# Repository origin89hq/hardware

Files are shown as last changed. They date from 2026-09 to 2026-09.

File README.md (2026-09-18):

<picture>
  <source media="(prefers-color-scheme: dark)" srcset="https://raw.githubusercontent.com/origin89hq/brand/main/logos/origin89-horizontal-white.svg">
  Origin89
</picture>

# Origin89 hardware

The boards and the enclosure of the Origin89 controller: a box that starts a
generator and manages a battery bank at a site four hours from a road, through
a Canadian winter, with nobody watching it fail. The reasoning behind the
circuits is in [docs/DESIGN.md](docs/DESIGN.md), the rules each board keeps
are beside the board, and this repository holds what was drawn from them and
what a fab needs.

| Board | Stage | Files |
| --- | --- | --- |
| [Controller, board A](boards/controller-a/) | prototype: revision A on the bench, the radios receive, board B's interlock not yet proven | EasyEDA source, Gerbers, BOM, pick-and-place, STEP, DXF, fabrication drawing |
| [Generator, board B](boards/generator-b/) | prototype: five boards assembled; the relay chains need a four-link rework, after which the interlock passes on the bench | EasyEDA source, Gerbers, BOM, pick-and-place, STEP, DXF |
| [Enclosure](enclosure/) | drawn, printing waits on a measured board | FreeCAD source, Blender presentation scene |

Nothing here is a validated product. A board that has been fabricated has not
necessarily been measured, and one that has been measured has not been
through a winter.

## Layout

Each board has a README with its status and revisions, its design source
under `easyeda/`, dated fabrication exports under `build/<date>/`, and, once a
board is on the bench, dated session write-ups under `bench/`. A file
that has been filed never changes: a changed export goes beside the old one
under a new date, so a board in someone's hands can still be matched to its
files. The STEP models are in Git LFS; install `git-lfs` before cloning or
they come down as pointer files.

EasyEDA names its exports after the board number and the date and puts them
in directories with parentheses. Do not file them by hand:

```sh
python tools/import_easyeda_export.py controller-a ~/Downloads/PCB1_2026-09-15
```

reads the date from the filenames, writes `build/2026-09-15/` with the same
names every export gets, `gerber.zip`, `bom.csv` and `bom.xlsx`,
`pick-and-place.csv`, `schematic.pdf`, `fabrication-layers.pdf`, `board.step`
and `board.dxf`, puts the `.eprj2` project under `easyeda/`, and refuses a
file it does not recognise or one that would change what is already filed.
Filing the 2026-09-09 exports through it reproduces the committed files byte
for byte, which is the check that the convention is the script and not a
memory.

## Checks

```sh
pip install gerbonara shapely
python tools/validate_gerbers.py boards/controller-a/gerber-rules.json boards/controller-a/build/2026-09-09/gerber.zip
```

It reads the copper layer by layer and reports each rule by number, so a
failure names the hole or the band. Which holes, which keep-out radius and
which voids come from the board's `gerber-rules.json`, so the same script
checks the [camera board](https://github.com/origin89hq/camera) against its
own rules. It runs in CI on every push against the newest controller export.

## Licence

The design files, drawings and CAD are under the CERN Open Hardware Licence
version 2, weakly reciprocal ([LICENSE](LICENSE)): change the board and share
the change; build a product around it and keep the rest of that product to
yourself. The Python tools are under MIT OR Apache-2.0 ([LICENSE-MIT](LICENSE-MIT),
[LICENSE-APACHE](LICENSE-APACHE)). The Origin89 name and marks are not covered
by either; see the [brand repository](https://github.com/origin89hq/brand).

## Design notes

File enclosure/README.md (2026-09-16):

# Enclosure

The controller's shell, printed in MJF PA12, drawn around the finished board:
the board is the master dimension. `shoe.py` is the parametric FreeCAD source
for both boards' plates and shoes; `artwork.py` produces the face artwork and
the label strips; `insert_drawing.py` places the heat-set inserts. Run them
with `freecadcmd`:

```sh
freecadcmd enclosure/shoe.py      # writes enclosure/out/board-{a,b}-{plate,shoe}.stl
freecadcmd enclosure/artwork.py   # writes enclosure/out/artwork-*.{svg,png}
```

Printing waits on a measured board. [`blender/`](blender/) holds the
presentation scene built from these outputs and board A's STEP, which the
website renders from; [`render/`](render/) is the chain that builds it.

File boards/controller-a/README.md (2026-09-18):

# Origin89 Controller, board A

 First revision fabricated. On the bench since 2026-09-14: SWD, both crystals, the RTC and its backup cell, FRAM, NOR, CAN in loopback, the analogue inputs, the watchdog, RS-485 across all three channels, three DS18B20s and the ESP32's radio receive all pass. Switching the ESP32 rail after ten minutes off corrupted the MCU 22 times out of 22 and is open; brown-out is unmeasured; board B's interlock waits on a board B wiring fault.

This is the board that makes the decisions. An STM32G0B1 runs the control
logic; an ESP32-C6 module carries the radio; three RS-485 channels, one CAN
bus and two VE.Direct ports talk to the site's equipment; 1-Wire reads
temperature probes; FRAM and NOR flash hold state and the event log. It runs
from a 12 V battery bank directly. The generator contact is on
[board B](../generator-b/README.md), so no single fault on this board can
hold a genset running.

100 × 125 mm, 1.6 mm FR-4, four M3 mounting holes. All field wiring enters on
one edge through one gland plate.

Design source: [`easyeda/origin89-controller.eprj2`](easyeda/), the EasyEDA
Pro project of this board alone.
Fabrication outputs: [`build/2026-09-09/`](build/2026-09-09/), Gerbers,
[bill of materials](build/2026-09-09/bom.csv),
[pick-and-place](build/2026-09-09/pick-and-place.csv), schematic PDF, STEP
and DXF.
Rules the layout has to keep, numbered and with their reasons:
[LAYOUT-REQUIREMENTS.md](LAYOUT-REQUIREMENTS.md).
Firmware: [origin89hq/firmware](https://github.com/origin89hq/firmware); its
`docs/ARCHITECTURE.md` is the system design this board implements.

## Status of the exports

`build/2026-09-09/` is the export of this layout from the project that
holds the board alone. The revision A boards, the first JLCPCB order, were
made from the same layout exported nine days earlier from the project that
also held the generator and camera; that file differs from this Gerber set
only in 2 mm² of unconnected top-copper islands near (+17.8, −42.1), and
both pass `tools/validate_gerbers.py`. The fab's production package is kept
outside this repository with the rest of the order paperwork.

The pick-and-place is the one to assemble from: the crystal X1 moved 0.112 mm
in X after the first pick-and-place was written, and this file has it where
the boards were assembled. The STEP is in millimetres and carries every part
but U8, the chip antenna, which has no model; CN9's model was not a STEP one
at export time, so check its height against the JST drawing before trusting
the enclosure clearance there. `board.dxf` holds every layer in one file.

The mounting holes on the fabricated boards carry no copper on any layer,
read from the fab's own CAM: the two in the antenna band have nothing within
4 mm, and the two at the bottom edge meet the ground pour at the A-02
keep-out radius, under solder mask. A-03 holds.

## Revisions

| Revision | Export | What changed |
| --- | --- | --- |
| A | 2026-09-09 | First fabrication at JLCPCB, from this layout. Gerber check all clear. First bench session on 2026-09-14: both processors boot; SWD, both crystals, the RTC, FRAM, NOR, CAN in loopback, the analogue inputs, the watchdog, RS-485 between all three channels at 115200 8N1 and 9600 8N2, a DS18B20, the RTC across a power loss on its CR2032, and the ESP32's rail and UART to the MCU work. As built, the STM32 cannot program the ESP32 over serial, because the module's IO8 boot strap is unconnected; with IO8 held high by a hand-held wire to a 4.7 kΩ pull-up, the ESP32 entered serial download mode, took its first firmware through the STM32, and from then on restarted into download mode on command with no wire. The ESP32 received 11 Wi-Fi networks and 30 BLE devices. Board B's interlock could not be proven because board B's relay chains cannot close ([board B bench log](../generator-b/bench/2026-09-14.md)); brown-out is not yet measured, and a self-test crash at the ESP32 rail switch is open ([bench log](bench/2026-09-14.md)). Silkscreen check against the rev B rule `A-33`: fails, the silkscreen carries designators only (#12). |

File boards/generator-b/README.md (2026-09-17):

# Origin89 generator board, board B

 First boards assembled. On the bench since 2026-09-14: both relay chains skip the relay commons as built, so nothing closes. With four links per board, 4 to 6 and 13 to 11 on each relay, the interlock passes: 68 sequences, no failures, the contact dropping 4.34 s after the last kick ([2026-09-17](bench/2026-09-17.md)).

This board owns the generator contact. Board A asks for the engine over a
five-wire link with two logic lines, `RUN` and a once-a-second `KICK`; this
board closes a dry contact toward the genset's two-wire start input only while
both are true, through two relays in series driven by two different paths. A
stuck controller, a stuck GPIO or a lost link each opens at least one relay by
construction, and the relays' second poles report what the contacts did. There
is no microcontroller on it.

80 × 55 mm, two layers, contact nets 1.0 mm wide and held 1.5 mm from every
other net by a DRC rule, seven test pads.

Design source: [`easyeda/origin89-generator.eprj2`](easyeda/), the EasyEDA
Pro project of this board alone.
What it is and why, the `B-nn` rules and what the bench has to prove on the
first boards: [GENERATOR-BOARD.md](GENERATOR-BOARD.md).

Fabrication outputs, export of 2026-09-09: [`build/2026-09-09/`](build/2026-09-09/),
the Gerbers, the [bill of materials](build/2026-09-09/bom.csv), the
[pick-and-place](build/2026-09-09/pick-and-place.csv), the schematic PDF,
the STEP model with every part on it, and one DXF of every layer.

## Status

Schematic drawn and verified, PCB placed and routed, DRC clean. Five boards
ordered from JLCPCB and assembled. Bench proof happens on those boards. The
Gerber check in `tools/` has no rule file for this board yet; this board's
`B-nn` rules are checked on the bench.

First bench contact, 2026-09-14 ([bench log](bench/2026-09-14.md)): driven
from board A, both coils energize and both relays click, but the contact chain
and the feedback chain are wired from each relay pole's NC terminal to its NO
terminal (pins 6 to 8 and 11 to 9), and the commons, pins 4 and 13, are
unconnected. Neither chain can close. A rework of four wire links is proposed
and not yet tried.

## Revisions

| Revision | Export | What changed |
| --- | --- | --- |
| first boards | 2026-09-09 | Gerbers and BOM of the layout the five assembled boards were made from; pick-and-place, schematic, STEP and DXF exported the same day. Bench, 2026-09-14: K1 and K2 are wired NC to NO with their commons unconnected, so CN10 and `FEEDBACK` cannot close ([bench log](bench/2026-09-14.md)). |

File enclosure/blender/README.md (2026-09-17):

# Blender presentation scene

`origin89.blend` is the controller as the website and documentation show it:
the enclosure meshes from `shoe.py`, board A imported from its STEP, the
satin-black finish, both label options, editable cable curves, ten cameras
and a studio light rig. Textures and the Michroma font are packed into the
file. It is stored in Git LFS; install `git-lfs` before cloning.

It is a presentation of the drawn design, not evidence about a board. Change
dimensions in `shoe.py` and rebuild; use Blender for finish, cables, lights
and cameras.

## Controls

Select **O89 Controls** in the Outliner, then open **Object Properties → Custom
Properties**:

| Control | Use |
| --- | --- |
| `production_label` | Switch between the clean editable text and the production transfers from `artwork.py`, including their QR code and specification table. |
| `cover_lift_mm` | Lift the cover, its labels and its light pipe to expose the PCB. |
| `show_enclosure` | Hide the cover and mounting plate for a board-only view. |
| `show_cables` | Hide the harness. |
| `show_bus_layout` | Replace the harness with an illustrative RS-485 daisy chain and 1-Wire trunk with short sensor taps. Use the Wiring camera. |
| `show_cable_sleeve` | Hide or show the braided sleeve and side retaining straps. The jacketed cables inside stay editable. |
| `led_on` | Toggle the single status indicator. |

The numbered collections separate CAD, PCB, connector proxies, clean text,
production artwork, cables, lights and cameras. Move the whole product with
`Product | move or rotate the whole controller`. Units display millimetres;
one internal Blender unit is one metre.

The saved scene uses the Hero camera. The others show the front, left and
right ports, the PCB, the exploded assembly, cable detail, connector
inspection, harness and wiring. **Connector inspection** lifts the cover
18 mm, so from that camera the port labels appear one position left of their
plugs; the closed views line up. **Wiring** shows one RS-485 bus serving
three example devices and one 1-Wire bus serving three probes; the device
shapes and distances are illustrative.

## Render

These commands read the saved `.blend` and never save over it. Run them from
the repository root. Tested with Blender 5.2.1 LTS.

```sh
blender --background --python-exit-code 1 \
  --python enclosure/blender/render_scene.py -- --view hero --studio
```

`--view` is one of `hero`, `front`, `left`, `right`, `pcb`, `exploded`,
`cables`, `wiring`, `connectors` or `harness`. `--label clean|production`
overrides the saved label choice, `--led-on`/`--led-off` the status light.
Omitting `--studio` gives a transparent PNG. Use `--scene` for a saved
variant, `--size 960 --samples 32` for a draft and `--output` to choose the
destination; the default is the ignored `previews/` directory. Each render
writes a JSON file with its camera, controls and projected light-pipe
position. Cable detail, connector inspection, harness and wiring use a 16:10
frame.

The website's Controller film, stills and 3D model are rendered from this file
by the scripts in [`web/`](web/); the website records the file's SHA-256 beside
them.

## Cable presentation

The three RS-485 leads and the bottom 1-Wire lead have graphite Cat5e jackets
(illustrative 5.2 mm diameter), an exposed twisted pair and a third conductor.
The 12 V lead has a separate power jacket with red/black conductors. CAN,
VE.Direct and the left-side leads keep their own cable types. LNK needs the
VH harness specified in `boards/generator-b/GENERATOR-BOARD.md`; Cat5e is
not a substitute for these leads.

Below the connector branches, the jacketed leads gather inside one charcoal
braided sleeve, about 25 mm outside diameter. Sleeve size, weave and strap
placement are presentation choices, not manufacturing CAD. The bus layout
view hides the sleeve so its routes stay readable.

The colour convention below is recorded inside the `.blend`. It is **not** an
Ethernet pinout or a published Origin89 wiring standard:

| Port | Pin 1 | Pin 2 | Pin 3 |
| --- | --- | --- | --- |
| RS-485 CN2/CN3/CN4 | Orange: A | White/orange: B | Green: GND |
| 1-Wire CN8 | Orange: OW_VCC | Blue: OW_DATA_F | White/blue: GND |
| CAN CN5, dedicated cable | Grey: CANH | White/grey: CANL | Green: GND |

Pin order and nets were checked against the `PAD_NET` records of the
2026-08-31 EasyEDA project. CN11 on the side and CN8 on the bottom share the
same 1-Wire nets; the layout uses CN8. Unused Cat5e cores stay insulated
inside the jacket.

RS-485 runs device to device with termination at the two bus ends; 1-Wire
uses one trunk with short taps. The scene does not specify distances or cable
suitability. Cat5e differs in impedance from typical 120-ohm RS-485 cable, so
termination and run length must suit the real design. See
[TI's RS-485 design guide](https://www.ti.com/lit/an/slla272d/slla272d.pdf) and
[Analog Devices' long-line 1-Wire guidelines](https://www.analog.com/en/resources/technical-articles/guidelines-for-reliable-long-line-1wire-networks.html).

## Rebuild from the CAD

**Rebuilding replaces the output file.** Save manual Blender edits under
another name first; rendering preserves them.

```sh
python3 enclosure/blender/rebuild.py --refresh-cad \
  --step boards/controller-a/build/<date>/board.step \
  --output enclosure/blender/origin89.blend --overwrite
```

`--refresh-cad` regenerates the enclosure STLs and production artwork from
`shoe.py` and `artwork.py` first; without it, `enclosure/out/` must already
hold them. The chain in [`../render/`](../render/) always refreshes the PCB
and textures. The runner uses the installed FreeCAD and Blender: on macOS the
applications in `/Applications`, overridden by `FREECAD_PYTHON`, `FREECAD_LIB`
and `BLENDER`. A restricted process sandbox can stop FreeCAD's CPU detection
and Blender's initialisation; run the applications normally in that case.

The 2026-08-31 STEP rebuilds in about a minute. The filed 2026-09-09 export
takes about seven and is not ready to replace it: its import leaves hundreds of
connector, header and inductor meshes stacked at the board centre, which the
debris filter in `assembly_glb.py` does not remove because they sit on the
board. Render the `pcb` view and check the centre before committing a rebuild.

## What the saved file was built from

The committed scene (SHA-256
`ba1af6a1d35ab9483d43a325ea3239f1ef33b9b08b4d51e17c7cd068e499e8b3`) was built before this
repository existed and records the paths of that earlier checkout:

- PCB: `3D_PCB1_2026-08-31.step`, SHA-256
  `36dd9b2bd17666da48dedbe704e6ce8f5d29558beba39459faf885ba20ff91f9`, 1,278
  shapes at 0.2 mm tessellation. This export predates the filed and fabricated
  `boards/controller-a/build/2026-09-09/board.step`, and the board's
  components differ between the two.
- Enclosure and artwork: `shoe.py` and `artwork.py` with the same geometry and
  label positions as `enclosure/` here.

A rebuild from `enclosure/` and the 2026-08-31 STEP renders the same as the
saved file, so the scene carries no manual edits beyond `build_scene.py`.

The connector bodies are datasheet envelopes from `shoe.py` with recessed
screw wells, wire-entry bores and hollow JST sockets for readability. They are
proxies; replace them with supplier CAD if exact connector detail matters.
The clean front text is a presentation variant; the fabrication artwork
remains the other label option.

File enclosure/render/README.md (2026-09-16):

# CAD to Blender

These scripts turn the enclosure CAD and a board STEP into the assembly that
[`../blender/build_scene.py`](../blender/build_scene.py) dresses into the
presentation scene. [`../blender/rebuild.py`](../blender/rebuild.py) runs the
whole chain; run the steps by hand only to debug one of them.

Two interpreters, because two ecosystems:

- **FreeCAD's Python** (`/Applications/FreeCAD.app/Contents/Resources/bin/python`)
  for anything that imports `shoe`/`artwork` or reads STEP. Put
  `/Applications/FreeCAD.app/Contents/Resources/lib` on `PYTHONPATH` when
  invoking it directly; the rebuild runner does this.
- **Blender** for assembly and the Cycles scene.

Intermediates land in `work/`, which is ignored and derived.

| # | Script | Runs under | Produces |
|---|---|---|---|
| 0 | `../shoe.py` | FreeCAD | `../out/board-{a,b}-{plate,shoe}.{step,stl}` |
| 1 | `../artwork.py` | FreeCAD | `../out/artwork-*.{svg,png}` |
| 2 | `frames.py` | FreeCAD Python | `work/frames.json`: envelopes, plugs and light pipes in the board frame |
| 3 | `board_glb.py --step <file>` | FreeCAD Python | `work/board-a.glb` and `board-a-source.json`, recording the STEP and its SHA-256 |
| 4 | `strips.py` | FreeCAD Python | `work/strip-*.png` and `strips.json`: one texture per port strip, read from `artwork.py`'s `STRIP_BANDS` |
| 5 | `textures.py` | FreeCAD Python | `work/tex-{a,b}.png`: the top transfers at texture size |
| 6 | `assembly_glb.py` | Blender | `work/assembly.blend` and `boxes-full.glb`: both boxes, boards, plugs, strips and cables |
| 7 | `../blender/build_scene.py` | Blender | `../blender/origin89.blend`: box A in the satin-black studio |

Step 6 still assembles box B, the generator board's enclosure, with an
envelope-only board. Step 7 removes it; `work/assembly.blend` is the place to
start a scene that shows both boxes.

Cycles is deterministic only on one machine with one seed. A re-render on
another machine differs in noise, not in content.

Gotchas that already cost time:

- The glTF exporter composes an unapplied object rotation about the world
  origin. Bake rotation into the mesh (`transform_apply`) before export.
- After a GLB round-trip, transforms are baked into vertices and every object
  origin is the world origin. Dress geometry by editing `v.co`, never
  `obj.scale` or `obj.location`.
- The EasyEDA STEP carries the board slab twice and has no bodies for THT
  connectors (0.8 mm outlines). `assembly_glb.py` keeps the lowest slab and
  stands in the datasheet envelopes from `frames.json`.
- `matrix_world` is stale after moving an object until
  `bpy.context.view_layer.update()`. Measure after the update, or a decal
  lands at the pre-move position.

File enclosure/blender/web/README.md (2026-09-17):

# Website renders

These scripts render the Controller media on the
[website](https://github.com/origin89hq/website)'s homepage: the hero film, the U7
and U8 chip views, the connection and integration stills, the Gerber artwork and
the 3D model. They read [`../origin89.blend`](../origin89.blend) and board A's
filed export in `boards/controller-a/build/2026-09-09/`, and never save over
either. Like the scene, the renders present the drawn design; they are not
evidence about a board.

The website packages the outputs with `apps/website/scripts/package-home-media.mjs`
and records this repository's commit and the SHA-256 of the scene, `gerber.zip`,
`pick-and-place.csv` and `bom.csv` beside them. The site miniatures on the same
page come from origin89hq/brand, `situations/scenes/site-miniatures/`.

| Script | Runs under | Writes |
| --- | --- | --- |
| `gerber_layers.mjs` | Node, through npx | `gerber-layers/`: `top-{copper,pads,silk,board}.png` masks at 64 px/mm and `top-layers.json` |
| `gerber_art.mjs` | Node, through npx | `gerber-art/`: `gerber-u7.webp`, `gerber-board-dim.webp`, `trace-mask-{u7,board}.webp` and `board-albedo.jpg` for the GLB |
| `build_detailed_board.py` | Blender | `controller-detailed.blend`, the scene the renders below use |
| `board_detail.py` | Blender, imported by the script above | parts and the board material |
| `render_film.py` | Blender, on the detailed scene | `film/frame-NNNN.png` (1920 × 1080) and `film/anchors.json` |
| `render_chips.py` | Blender, on the detailed scene | `chips/u7.png` and `chips/u8.png` (1000 × 1000, orthographic) |
| `render_studio.py` | Blender, on the detailed scene | `studio/connect-*.png` (1760 × 1210) and `studio/integrate-controller.png` (1600 × 1800) |
| `export_glb.py` | Blender | `controller-raw.glb`, compressed to `controller.glb` with gltf-transform |

Every Blender render has a transparent film. The detailed scene replaces the
STEP's box components with parts placed from pick-and-place, marked from the
BOM, and textures the board from the Gerber masks. Connectors keep the scene's
datasheet-envelope proxies. The ESP32 module's matrix code is a fixed
pseudo-random pattern. `render_chips.py` scales the laser marking and mattes
the finishes for the flat top view. `render_film.py` moves one camera without
cuts through its stations along periodic curves, bakes every camera, object and
light value on each frame, and renders with motion blur. It projects anchor
points on the board through the camera into `anchors.json`, with the window in
which each callout is shown; the website places its callouts from that file, so
change the stations, windows, anchors and callouts together.

## Run

Requires Blender 5.2 on a Mac with a Metal GPU (the render scripts select Metal
devices), Node with network access for `npx`, the scene from Git LFS, and
Inter Tight 600 for the part markings: `fonts/InterTight-600.ttf` in
origin89hq/brand, also shipped in the `@origin89/brand` package. This
repository has no Node workspace; npx installs the pinned packages for each run.

From the repository root, on a clean checkout:

```sh
M=/tmp/home-media
BLENDER=/Applications/Blender.app/Contents/MacOS/Blender
FONT=/path/to/brand/fonts/InterTight-600.ttf
WEB=enclosure/blender/web

# 1. Gerber masks and artwork
unzip -o boards/controller-a/build/2026-09-09/gerber.zip -d "$M/gerber"
npx --yes --package sharp@0.35.3 --package pcb-stackup@4.2.8 -- \
  node "$WEB/gerber_layers.mjs" --gerbers "$M/gerber" --out "$M/gerber-layers"
npx --yes --package sharp@0.35.3 -- \
  node "$WEB/gerber_art.mjs" --layers "$M/gerber-layers" --out "$M/gerber-art"

# 2. Detailed board scene (keep $M/gerber-layers: the scene links those PNGs)
"$BLENDER" --background --python-exit-code 1 --python "$WEB/build_detailed_board.py" -- \
  --layers "$M/gerber-layers" --font "$FONT" --output "$M/controller-detailed.blend"

# 3. Film, chips and studio stills
"$BLENDER" --background --python-exit-code 1 "$M/controller-detailed.blend" \
  --python "$WEB/render_film.py" -- --out "$M/film"
for chip in U7 U8; do
  "$BLENDER" --background --python-exit-code 1 "$M/controller-detailed.blend" \
    --python "$WEB/render_chips.py" -- --out "$M/chips" --chip "$chip"
done
"$BLENDER" --background --python-exit-code 1 "$M/controller-detailed.blend" \
  --python "$WEB/render_studio.py" -- --out "$M/studio"

# 4. Web model
"$BLENDER" --background --python-exit-code 1 --python "$WEB/export_glb.py" -- \
  "$M/controller-detailed.blend" --board-albedo "$M/gerber-art/board-albedo.jpg" \
  --output "$M/controller-raw.glb"
npx --yes @gltf-transform/cli@4.5.0 webp "$M/controller-raw.glb" "$M/controller-webp.glb"
npx --yes @gltf-transform/cli@4.5.0 meshopt "$M/controller-webp.glb" "$M/controller.glb"
```

Hand `$M` and this checkout to the website packager. It reads `film/`, `chips/`,
`studio/`, `gerber-art/` and `controller.glb`, and `dioramas/` from the brand
script unless `--only` leaves the miniatures out. It refuses scene or fab inputs
that differ from the checked-out commit.

Run one Blender process at a time; the renders share the GPU. The film is 1440
frames (48 s at 30 fps) at 40 samples, about 5 s per frame on an M2 Max, so
about two hours. Check the motion first with `--size 640x360 --samples 8`, about
35 minutes for the whole loop. The render skips frames that already exist, so an
interrupted render resumes. Changing one station only changes the frames from
two stations before it to two stations after it, so delete and render those; `--frames 1-120` renders part of the loop and
`--anchors-only` rewrites `anchors.json` without rendering and reports how much of
each callout window keeps its anchor in frame. The chips and stills (96 samples) take seconds each;
`render_studio.py --only` renders a subset. The Gerber masks take about a minute
of CPU.

With sharp 0.35.3, the two Gerber scripts reproduce the website's current Gerber
artwork byte for byte. New Cycles renders are not expected to match the published
hashes.

A new fabrication export changes the date in three places: `FAB_BUILD` in
`board_detail.py`, the `unzip` path above, and the packager's input paths.
`gerber_layers.mjs` stops if the board outline is no longer 100 × 125 mm, which
the board texture's UV mapping assumes.

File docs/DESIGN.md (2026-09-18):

# Circuit design

Why the circuits are what they are: the generator interface, the power path,
the buses, the parts, and what was checked before any board was laid out. The
rules a layout has to keep are elsewhere and own the values:
[`LAYOUT-REQUIREMENTS.md`](../boards/controller-a/LAYOUT-REQUIREMENTS.md)
(`A-nn`) for board A and
[`GENERATOR-BOARD.md`](../boards/generator-b/GENERATOR-BOARD.md) (`B-nn`) for
board B, each stating what revision A was built with beside a rule revision B
changed. Where a value here has moved since revision A, the rule wins and this
document says so. The system side, what the controller decides and why the
comms processor may not, is the firmware's
[`ARCHITECTURE.md`](https://github.com/origin89hq/firmware/blob/main/docs/ARCHITECTURE.md);
this document does not repeat it.

It grew out of origin89's `CONTROLLER-V1.md` (2026-08-03), split three ways on
[origin89hq/origin89#16](https://github.com/origin89hq/origin89/issues/16): the
circuit reasoning came here (#50), the system design went to the firmware, and
the plan became origin89hq/firmware#3 and its milestones.

## Two boards, and why the split exists

The run-enable watchdog lives on board B with the relays it drops. That is what
makes the split a safety decision rather than a packaging one: the plug between
the boards carries only *please run*, so every way it can fail, a connector
backed out, a cable pulled, a cold joint at −30 °C, stops the kick arriving and
opens the contact. A lost link is the safe state by construction. Put the
watchdog on the controller instead and the same fault is a cracked joint that
nothing announces.

The second reason is dirt. The 60 ft pair to the generator is the filthiest
thing touching this design, and on its own board that energy never reaches the
one carrying the MCU, three RS-485 channels and CAN. `LAYOUT-REQUIREMENTS.md`
§1 states the same split for a layout house.

## The generator interface

### A maintained contact, and a kit that owns the engine

Site A's generator carries a wireless and 2-wire remote-start kit. The kit
maker's own answer, when asked:

> "You can touch the 2 terminals in that connector together with a screwdriver.
> When connection is made between these 2 terminals the generator should crank
> and start. When you release the connection the generator will shut off."

**A maintained contact, not a pulse. Closed is running, open is stopped.** The
kit owns the engine switch, the fuel valve, the choke, the crank sequence and
the retries; the controller owns deciding. So the generator interface is one
dry contact out and one AC meter in, not six inputs and four outputs, and there
is no generator module in V1: a dry contact over 60 ft has no voltage drop and
no comms link to lose. A module becomes a product feature when a run is long
enough that pulling twelve conductors beats pulling one shielded pair, or when
a site has a genset without a start kit. A genset with a controller panel of
its own changes that site from *drive a contact* to *talk to a controller over
Modbus*, which the buses below already carry.

### The electrical design

```text
   board A, controller          │          board B, generator
                                │
STM32 ── RUN ───────────────────┼──► relay B    rev A: RUN drives the coil
      ── KICK ──────────────────┼──► monostable ──► relay A
      ◄─ FEEDBACK ──────────────┤◄── the relays' second poles, in series
         12 V · 0 V ────────────┤
                       CN9, JST VH
                                    relay A ── relay B ── F1 ── CN10 ── 18/2 ── [lockout] ── 2-wire input
```

**Two relays in series, independently driven.** A maintained contact means a
welded relay runs the generator until the tank is empty. One weld no longer
does that. Both welding is still possible, which is what the alarm and the
lockout switch are for. The two-in-series claim holds only if nothing common
can hold both, so the two coils have two drivers from two sources and never a
shared gate net (B-01), and the relays are rotated to each other so a surge
through the pair they share does not find them the same way (B-14).

**A run-enable watchdog in hardware.** The contact stays closed only while
firmware keeps kicking a retriggerable monostable, a 74HC123 whose Q is the
level the relay wants. Firmware that dies stops kicking, the contact opens
after the window, and the generator stops: dead controller means stopped
engine, guaranteed by a part that runs no code. The kick line never reaches a
coil directly, because a `KICK` stuck high is exactly the failure the
monostable exists to catch (B-02). On revision A the window is about 4.5 s by
design and 4.3 s on the bench, inside the 3.0–6.5 s the contract allows and
drifting with board temperature, so the firmware measures what it sees and
never assumes (#22, and the
[bench log of 2026-09-17](../boards/generator-b/bench/2026-09-17.md)).

**The claim the first design made, and revision A did not keep.** The design
said a brief controller reset, a watchdog or a brown-out, would re-kick before
the window expired and the running generator would never notice. Revision A
does the opposite: `RUN` drives relay B's coil directly and holds the
monostable in reset while low, so the moment the controller's pin stops
driving, board B's pull-down reads *stop*, relay B opens and the monostable
clears, and every controller reset opened the contact at once (#18). Revision
B keeps the promise with a latch rather than a delay: relay B follows `RUN`
*sampled on each `KICK` edge*, so a deliberate stop lands within one kick and
only a silent controller rides through, bounded by a window widened to 15 s
(B-19, B-20). The window is budgeted: the controller's 8 s
watchdog at the LSI's worst case, 8.8 s, plus 3 s for reset-to-first-kick,
which the firmware owes as a requirement, plus margin (#51). Revision B is
drawn and not yet proven; B-21 is the table the bench runs against.

**A lockout switch at the generator end.** Open means the software is
physically disconnected regardless of what it believes. It is the service
lockout: cut it before touching the engine and nothing remote can crank it
while your hands are in there. The kit manual's own wiring diagram puts
an emergency stop switch in series in the junction box, which is this switch.
It is a different thing from the auto/off/manual selector at the controller,
which is an operator override; the firmware's `ARCHITECTURE.md` has both.

**Contacts for a dry circuit.** Nobody had measured the 2-wire input's
open-circuit voltage or short-circuit current when the first design was
written, and a low-level dry-circuit load is exactly where ordinary silver
contacts fail to make, because there is not enough energy to break through the
oxide film. A sweep of the remote-start section of every 2-wire generator
controller's manual found each input switched to negative at a few milliamps
behind a pull-up, one maker's at 12 V and 6 mA, another's at 5 V and
current-limited, so
board B carries the G5V-2's gold-clad bifurcated crossbar contacts, specified
from 10 µA to 2 A. That closes the question for the class; the site's own
figures still confirm it, and on revision B they size the clamp (below).

**The fuse and the clamp.** The kit's internal contacts are fused with its own
5 A main fuse and its manual says additional protection may be required, so
the run contact carries its own fuse sized below it: a 2 A 5 × 20 in a holder,
replaceable without a tool, because a soldered fuse four hours from a road is
a dead site and a fuse above the kit's makes the kit's blow inside a box
nobody opens (B-05). Across the pair at the terminal sits a bidirectional TVS,
bidirectional because the input's polarity is never guaranteed. On revision A
it is one part, and a single shorted TVS joins the pair with no relay involved
and the fuse not in the path, the one part outside the interlock that can
start the engine; revision B fits two in series, each blocking the site's
start-input voltage alone (B-06, #19). The 60 ft pair is the surge path, so
its copper is 1.0 mm and nothing else comes within 1.5 mm of it (B-04, B-13).

**The link between the boxes.** Five conductors, `CN9` to `CN9`, a locking
JST VH at both ends, under 3 m, indoors, unshielded: nothing on it carries
more than the two coils. The pin order is board A's and is written on both
silkscreens, because two boards that disagree on a locking connector's pin
order is 12 V on a logic pin with a connector that cannot be plugged the
other way to fix it (B-09). On revision A the three logic lines run straight
from the STM32's pins to the cable, and two of them are the pins ST's system
bootloader drives as FDCAN1 on an empty flash, which every board has before
programming and after an interrupted update: the bootloader pulls `RUN` above
board B's gate threshold and can pulse `KICK`, so the start contact can close
with no firmware running. The monostable guards against a stuck controller,
not against a bootloader that looks like one (#30). Revision B moves the three
nets to pins the bootloader does not configure, behind a series resistor, a
TVS and a pull-down at board A's end (A-34), and the firmware never leaves an
empty-flash window; the firmware's `ARCHITECTURE.md` carries that half.

### Proof of running is measured at the panel

A contact closing is not an engine catching. The `starting` to `running`
transition needs AC the controller can read itself, and the earlier answer, a
smart plug on Wi-Fi, breaks the one rule on the machine where not knowing the
state is most dangerous; the firmware's `ARCHITECTURE.md` makes that argument.
The choices for sensing:

| | | |
|---|---|---|
| **An RS-485 AC meter** at the panel, on the charger's supply | ~$25 | Voltage *and* frequency. "120 V at 60 Hz" is far better evidence an engine caught than "current is flowing" |
| **Optocoupled AC detect** into a GPIO | ~$5 | Simplest and most direct. What the smart plug plan replaced |
| **Charge current on the bank**, via the DC meter already there | free | Indirect, and solar charges too; it cannot tell the two sources apart |

The AC meter is the choice: frequency is the discriminator current alone
cannot provide. Its framing differs from the DC meters', so it cannot share
their bus; which port it takes is in the bus map below. At site
A the generator's 120 V output already runs to the cabin and lands on the
charger outlet, so proof of running is measured there and nothing but the dry
contact pair crosses to the garage.

### What the kit's manual says, and which lines change a design

From the kit's 2-wire installation manual:

> The manufacturer temperature range specification for the choke actuator is
> **−20 °C to +60 °C**. It is not recommended to start the generator with the
> remote start outside this range. **Choke actuator failure may result.**

The coldest night is exactly when the generator is most needed and least able
to be started; that is the central tension of the product stated by the
vendor. It is a behaviour decision, made deliberately and logged with the
outdoor temperature, and it belongs to the firmware (`ARCHITECTURE.md`, the
generator). What it asks of the hardware is an outdoor probe, which the 1-Wire
port carries.

- **"The generator ignition switch MUST be left on for the 2-wire start to
  operate."** Somebody switching it off disables remote start with no
  indication at our end. Proof of running at the panel is what catches it.
- **"Start Module internal contacts are fused with the start module main
  fuse. Additional circuit protection may be required."** The kit ships a 5 A
  fuse; B-05 is the answer.
- The manual states neither the input's open-circuit voltage nor its
  short-circuit current, so the meter is still the only way to learn them.

### Still to confirm at the site

- **Whether opening the 2-wire contact stops a fob-started generator.**
  Release means shut off was described for the 2-wire path only. If the fob
  latches, the firmware's `stop not honoured` is routine rather than rare, and
  the selector's *Off* position is the only honest way to hand control back.
  One email to the kit's maker.
- **The 2-wire input's open-circuit voltage and short-circuit current.** A
  meter across the connector, a minute. It confirms the site sits inside the
  class the G5V-2 covers, and on revision B it sizes each of B-06's two series
  clamps. Still unmeasured.
- **How the cable runs and whether the garage shares the cabin's earth.**
  `LAYOUT-REQUIREMENTS.md` §5 items 5 and 6: aerial means surge protection
  sized for it, buried means rodents, and a detached garage with its own rod
  means the pair bridges two earthing systems.

## Power

### The supply is the bank

The controller runs from the battery bank through its own validated input and
protection path, with no inverter and no computer kept on to host it, because
continuous consumption takes energy from the bank through the season when it
is weakest. Revision A was built for a 12 V bank only, with the bank itself on
the `V12` net; revision B takes a 12 V or a 24 V bank and regulates a 12 V
rail from it for everything past the front end (A-20, A-20e). 48 V banks are
out of scope by decision: such a site already runs its 24 V loads from a
converter of its own, and the controller connects to that (§5 item 11). The
input range has to account for the charging voltage and its transients as
well as the nominal, which is why A-20 is written from the highest voltage a
24 V charger applies with equalisation included.

Measure total input power on the assembled controller for idle, normal
polling, active communications, energised outputs and peak demand, converters,
transceivers and powered peripherals included, and record the communications
state and duty cycle with any daily energy figure. Until those measurements
exist, public copy states the low-consumption goal without a numeric saving or
runtime promise. An MCU's idle current is not the whole device's consumption.

### The rails

Two TPS54331 bucks, 5 V for the transceivers and 3.3 V for everything else.
The 3.3 V converter runs from `V12` directly rather than from the 5 V rail, so
a fault in the transceiver supply cannot take the MCU down with it. On
revision B one 60 V-class buck sits ahead of both and makes the regulated 12 V
they run from; below 12 V it passes the bank through, about 10.2 V at a
discharged 12 V bank, which the TPS54331s regulate from and board B's coils
pull in at (A-20e). Putting that converter on board A rather than on board B
keeps the bank voltage out of the safety chain and board B a 12 V board on
any bank. Every rail that leaves the board, board B's coil supply, the 4-pin
RS-485 port's 5 V, the 1-Wire supply and the tank loop, goes through its own
current limit with a fault flag the MCU can read, so a pinched cable is a
diagnosis and not a blown inlet fuse (A-20b to A-20d, A-24, #47).

The comms processor's 3.3 V is a switched sub-rail, gated by the MCU so a
wedged radio is recoverable without a drive. Revision A's switch defaults off
through every controller reset, which nobody chose, and switching it on after
minutes off corrupted the MCU 22 times of 22 on the bench; revision B's switch
is slew-limited and defaults on, and the controller takes ownership once it
has booted (A-23, §5 item 8, #5). The policy that decides when the radio is
cut is the firmware's, in `ARCHITECTURE.md` under the safety architecture.

### The buck's under-voltage lockout is deliberately low

`EN` divider 330 kΩ / 51.1 kΩ on revision A: the converter starts at 8.99 V and
stops at 8.00 V, about 1 V of hysteresis. Low on purpose, and the reason is the
whole point of the box. The first values, 75 kΩ / 10 kΩ, put the stop
threshold at 10.32 V with only 225 mV of hysteresis: the controller would
power down while the bank still had usable charge, and the controller is the
thing that decides to start the generator that recharges it. It would switch
off at exactly the moment it was most needed and stay off until somebody drove
out. Protecting the bank from deep discharge is the charge controller's
low-voltage disconnect, not the buck's. The thin hysteresis was a second
problem: a bank hovering at the threshold chatters the whole controller.

Computed with TI's equations 1 and 2, which include the internal 1 µA and 3 µA
`EN` current sources; treating `EN` as a plain divider gives a materially
different and wrong answer. Revision B's front-end buck sees the bank instead,
and the same argument sizes its enable network; its values are not yet in the
rules, and the bench measures the brown-out recovery either way (§5 item 9).
The firmware's radio policy has to sit above whichever threshold the front end
stops at, or it never runs.

### The buck's compensation, recomputed

10 kΩ and 10 nF in series on `COMP`, 100 pF from `COMP` to ground, on both
rails. The original 3.09 kΩ / 3.3 nF put the compensation zero at 15.6 kHz
while the loop crossed over at 5.7–9.5 kHz. A zero above crossover boosts
nothing where it matters, and the worst-case phase margin was about 20° on
both rails across the plausible range of ceramic derating and load: a peaky,
ringing rail rather than an obviously dead one, the kind that survives a bench
test and browns out under the comms processor's transmit bursts. Recomputed
against the real 15 µH filter to at least 74°.

The model was checked against the datasheet's own worked example first: it
reproduces TI's 3.3 V design at 22 kHz and 74° against their stated roughly
25 kHz and better than 60°, because a loop model nobody has calibrated is an
opinion. 10 kΩ and 10 nF were already in the BOM and the parts they replaced
were used nowhere else, so the change removed a line rather than adding one.
A-30 puts the network on the `COMP` pin itself, with the 100 pF closest: a
loop with 74° on paper is still a ringing rail if the error amplifier's output
picks up the switch node over 20 mm of trace.

## The buses

### Transceivers go on the board, not on headers

Breakout modules are how the circuit was prototyped. They are not how it
ships. Every connector is a failure point, and a module on pin headers
through a few hundred thermal cycles beside a running generator is an
intermittent fault that presents as a flaky bus and costs a week. Layout
cannot be controlled through wires: the transceiver belongs near the
connector, the TVS at the connector rather than after the chip, the pair
spaced deliberately, the ground reference short. And the transceiver IC costs
a dollar or two against six for the module, before its board, its headers and
somebody plugging it in. What carries across from the bench modules onto the
layout:

| | Why |
|---|---|
| **MAX13487E / MAX13488E**, auto-direction | No DE pin, no turnaround timing to get wrong: one category of bug removed permanently for about $2 a channel. **It does not remove the bias resistors**; see below. The one thing the auto-direction part cannot do is stop driving while the MCU is in reset, so each `TX` net carries a pull-up (A-41, #28) |
| **TVS on A/B, at the connector** | SM712 class: asymmetric 7 V / 12 V, matching RS-485's −7 / +12 V common-mode range, which a symmetric SMAJ12CA does not. **Pin 3 is the common on both the SM712 and the PESD1CAN; the middle pin is a signal line.** Both were first wired with pin 2 to ground, which would have left the A line with no path to ground and a spurious clamp across the pair. Neither symbol names its pins, so the netlist looked plausible and was wrong (A-11c) |
| **Selectable termination**, a header and shunt | Whichever device sits mid-bus must stop terminating without a soldering iron. Shipped fitted, placed above its own connector and silkscreened with the bus name, because the first placement left three of four jumpers nearest a bus they do not terminate (A-13, A-32) |
| **Activity LEDs** | On the receiver output, so they show something *else* on the bus talking, which is what somebody with the cover off wants to know. Revision A's are far brighter than an electrical room needs; revision B drives them at 0.2–0.5 mA (A-14) |

**Slew rate is the one place the two parts differ meaningfully**, and the
intuition is backwards: the MAX13487E's slew limiting exists to reduce
reflections and EMI on long cable, so the *slower* part is the right one for a
long run. Both cover 115200 many times over, so speed decides nothing.

### Bias is mandatory, and 560 Ω was not enough

The MAX13487E datasheet calls the A/B pull-up and pull-down *required for
proper operation*, because the direction state machine reads the current A−B
state and the receiver threshold is ±200 mV, not fail-safe. An unbiased idle
bus is indeterminate and the state machine's own input is undefined. This was
nearly omitted on the belief that the part had a true fail-safe receiver; it
does not.

The first design put 560 Ω to +5 V and to 0 V at the master end, and revision
A was built with it. **Superseded by A-13c.** 560 Ω leaves 254 mV of idle
differential with two terminators and 172 mV with three, inside the undefined
band, and a mid-bus board with its jumper still fitted is the three-terminator
case; two terminators keep only 40–50 mV of margin against noise on a long
cable. Revision B sizes the bias to stay above 200 mV with three terminators,
about 390 Ω, settled on a real cable against the bias of the other devices on
the site's buses before the order (#26).

### The isolated bus is the exception, and none is fitted

The criterion is two separate earthing systems, not distance. A 30 m run
between devices bonded at the same panel shares a ground and needs nothing;
two buildings ten metres apart with a rod each do not, and do. An
ADM2582E-class part, isolated transceiver and isolated DC-DC in one package,
has explicit DE and RE pins; there is no common isolated auto-direction part.
So a bus that crosses an earthing boundary uses the USART's hardware
driver-enable, which the STM32 outputs on the RTS pin (below), and the
firmware supports both modes regardless.

No isolated channel is fitted, deliberately. At site A nothing but the dry
contact pair crosses to the garage, so the bus would have no consumer, and an
ADM2582E with an 8 mm barrier would cost board area for it. A detached garage
with its own rod is what would reopen this (`LAYOUT-REQUIREMENTS.md` §5).

### Bus map

The VE.Direct family is the trap here, and it costs a bench day: those
products do not speak Modbus RTU on RS-485.

| Device | Bus |
|---|---|
| Charge controllers speaking Modbus RTU | RS-485, 115200 8N1 |
| DC meters | RS-485, Modbus RTU, 9600 **8N2**; passive on the bus side and fed 5 V over the cable, so they take the 4-pin port (A-37) |
| The AC meter at the panel | RS-485, 9600 8N1, a third framing, so it cannot share the DC meters' bus |
| Origin89 modules (V2) | RS-485, Modbus RTU, 9600, plus an attention line |
| Most lithium BMSes | CAN, 500 k |
| VE.Can and BMS-Can devices | CAN, 500 k |
| VE.Direct devices: shunts, battery monitors, MPPTs | **VE.Direct**: TTL UART, point to point, one port each |
| VE.Bus inverter-chargers | Proprietary; read through their own gateway over Modbus TCP, a client's job |
| DS18B20 | 1-Wire |

Three RS-485 channels carry three framings, one each. Which connector carries
which is configuration in the firmware, with one constraint the board sets:
the DC meters need the 5 V pin, and only `CN4` has one. Revision A read a DC
meter on that port at 9600 8N2 as soon as it had 5 V from elsewhere, 119 of
120 polls (#34). When the V2 modules arrive they take a channel, and the AC
meter is the port that then gets forgotten until a respin, which is why the
serial budget below counts it.

**Modules speak Modbus, not a house protocol.** The same driver stack then
reads them and third-party gear, any twenty-dollar USB dongle debugs them, and
every Modbus tool becomes test equipment. Keep our own register map; do not
invent framing. Modbus cannot let a leak sensor interrupt, so a shared
open-drain attention line on the same cable does that: any module pulls it low
to mean *poll me now*. One wire, decades old.

### VE.Direct is point to point, and needs isolation

Two VE.Direct ports are where the shunt lives, and the first design priced
them as nearly free, a UART and a level shift. Revision A built them that way,
with 1 kΩ in series and no level shift, listening on pin 3, its own TX
position, so they work only with a straight cable and only with 3.3 V
products. **Superseded by A-38.** The maker's MPPTs drive 5 V, which exceeds
the STM32's pin limit whenever the internal pull-up is on or the board is off,
and its own FAQ asks for galvanic isolation because the product side has
little protection of its own. Revision B listens on pin 2, the producer's TX,
through a digital isolator per port powered from the port's pin 4 within the
port's documented 10 mA limit, working at both levels the products drive, and
defaulting high on the board side while the product side is unpowered so an
unplugged port reads idle by the part's own fail-safe (#27). No VE.Direct
device has been on the bench yet; that is §5 item 9.

### Seven serial ports against eight instances

An earlier draft said the part has six USARTs and treated the budget as
closing at zero margin. It has eight independent serial instances,
USART1/2/3 (FULL), USART4/5/6 (BASIC), LPUART1/2 (LP), per RM0444 Rev 5 Table
179, and the undercount is the only reason this looked tight.

| Port | Instance | Why that one |
|---|---|---|
| ESP32 link, 921600, CTS+RTS | **USART1/2/3** | Only the FULL set has a FIFO. A BASIC instance at 921600 is a byte-at-a-time interrupt storm |
| Isolated bus, hardware DE, if ever fitted | **USART1/2/3** | FULL, and DE needs an instance whose RTS pin is free (below) |
| Two RS-485 channels, auto-direction | USART4/5/6 | No DE and no flow control needed, so BASIC is enough at 9600 |
| **The AC meter, proof of running** | USART4/5/6 | **A seventh port.** 9600 8N1 cannot share the DC meters' 8N2, and once the V2 modules take a channel it cannot share theirs either |
| VE.Direct ×2, RX only | **LPUART1/2** | Needs neither DE nor flow control, and LPUART can run while the core is stopped |
| Console | not a UART | `defmt` over RTT on SWD |

Seven allocated, one spare. Two silicon facts constrain the schematic:

- **The driver-enable signal is output on the RTS pin** (RM0444 §33.7.5,
  `CR3.DEM`). There is no separate DE ball. An instance does hardware RTS *or*
  hardware DE, never both. That does not collide here: the ESP32 link needs
  RTS and CTS and drives no transceiver, and Modbus RTU has no flow control.
  But a schematic drawn with a separate DE output is wrong, and an RTS pin
  spent on DE is an RTS pin gone.
- **USART4/5/6 have no TX or RX FIFO** (Table 180), which is what forces the
  921600 link onto the FULL set.

## Part choices

| Decision | Choice | Reason |
|---|---|---|
| Controller | STM32G0B1 | 512 KB dual-bank flash for A/B updates, 144 KB RAM, eight serial instances, FDCAN. The M0+ has no FPU, which is fine for 1 Hz counting |
| Upgrade path | STM32H5 | If command authentication and secure boot ever need TrustZone and a ROM signature check. The firmware keeps its core HAL-agnostic so the swap stays cheap, and names its images by role for the same reason |
| Comms | Pre-certified ESP32-C6 **module** | Inherits ISED, FCC and CE. A bare chip costs roughly ten times more to certify. Its antenna wants a board cutout and 15 mm of clearance inside the box (A-15, #16) |
| Generator output | Two relays in series, independently driven, behind a hardware run-enable watchdog on their own board | A maintained contact means one welded relay runs the tank dry (above) |
| Relays | Omron G5V-2, DPDT | Gold-clad bifurcated crossbar contacts specified from 10 µA, for a dry-circuit load; the second pole is the feedback contact for free. Rated −25 to +65 °C, an accepted deviation on board B's industrial-grade rule (B-08) |
| Temperature range, board A | Commercial parts | The electrical room stays above 0 °C and is occupied. No −40 requirement and no conformal coating for V1 |
| Mains | **Never on the board** | Dry contacts only, driving contactors somebody else certified. Sidesteps CSA and UL as a category |
| Storage | FRAM **and** NOR | Different failure consequences, so different chips: FRAM for everything control-critical that must survive a cut mid-write, NOR for the log ring. What each holds is the firmware's |
| Override | Auto/off/manual selector at the controller; lockout switch at the genset | Two different needs, operator override and service lockout. Revision B adds a button the STM32 reads for the gestures the protocol needs (A-42) |
| Debug | SWD, 6-pin in ST-LINK order on revision B | Revision A's header carries no NRST, so a probe cannot connect under reset and the only recovery is a wire to a capacitor pad; the M0+ has no trace, so the SWO position is labelled NC (A-40, #29) |

## Before any board is laid out

Established against the datasheets: the part fits on LQFP64 with one spare
serial instance and spare I/O; revision A left 19 pins unused (§5 item 2).
LQFP48 does not fit, failing on raw pin count before alternate functions are
considered.

Five items were open before revision A, and four were called respin grade.
They were answered without opening CubeMX: `stm32-metapac`, which the firmware
already depends on through `embassy-stm32`, ships the pin and alternate-
function tables for every part, machine-extracted from ST's own database by
`stm32-data`. It is the same source CubeMX reads. If it were wrong the
firmware would not work either, which makes it a witness rather than a second
opinion.

| | What | Answer |
|---|---|---|
| 1 | **CTS pin availability** | **Not scarce.** USART1 CTS is on **PA11/AF1 and PB4/AF4**. The fear that there might be none was unfounded; nobody had looked |
| 2 | **FDCAN pin mapping** | **FDCAN1 TX** on PA12, PB9, PC5, PD1; **RX** on PA11, PB8, PC4, PD0, all AF3. The board uses PB9/PB8 |
| 3 | **PA11/PA12 remap** | **Moot.** With CTS on PB4 and RTS on PB3, the whole ESP32 link sits on PB6/PB7/PB4/PB3 and touches neither pad. Revision B keeps those link pins (A-39) |
| 4 | **Alternate-function numbers** | Superseded. Read from metapac 21.0.0, not from DS13560 Rev 1 of November 2020 |
| 5 | **DMA channel budget** | **12 channels**, DMA1 ×7 and DMA2 ×5, plus **DMAMUX1**, so any request routes to any channel and there is no mapping puzzle, only a count. Full demand would be 18, but nothing obliges a 9600-baud Modbus TX to use DMA. This one could never have forced a respin: it is a firmware allocation question, and it was ranked alongside four that were |

The lesson is about the ranking, not the pins. Four items sat at respin grade
for months on the strength of a contradiction in one datasheet table, and the
answer was sitting in a Cargo dependency the firmware already builds against.
Before declaring something blocked on a tool nobody has opened, check whether
the machine-readable form is already on the disk. CubeMX is still worth an
hour as confirmation before fabrication; it is no longer a gate.

The pin assignment is closed for revision A and reopened for revision B: `RUN`,
`KICK` and `FEEDBACK` leave the bootloader's FDCAN1 pins (A-34) and the button
arrives (A-42), each new pin checked against the metapac and against AN2606's
table of the pins ST's system bootloader configures. Two pins to remember when
moving anything: `PA4` and `PA5` are 3.3 V only, carry SPI to the NOR, and a 5 V
signal on either is a scrapped board (§5 item 3).

## Settled

Recorded so they are not re-litigated:

- **The generator interface** is a maintained dry contact, closed means run,
  and the start kit owns cranking, confirmed by its maker.
- **No generator module in V1.** A dry contact over 60 ft has no voltage drop
  and no comms link to lose.
- **The electrical room stays above 0 °C and is occupied**, so commercial-range
  parts on board A and no conformal coating for V1.
- **The generator run is 60 ft**, garage to panel, not the 100 ft an earlier
  draft carried. It changes nothing for a dry contact; it is recorded so
  nobody measures it a third time.
- **Nothing but the dry contact pair crosses to the garage.** Proof of running
  is measured at the panel, no RS-485 leaves the building at site A, and the
  isolated bus has no consumer there.
- **The 2-wire input's class is closed, the site's figures are not**, and on
  revision B they size B-06.

## What lives elsewhere

- The rules and their values, per revision: `A-nn` in
  [`LAYOUT-REQUIREMENTS.md`](../boards/controller-a/LAYOUT-REQUIREMENTS.md),
  `B-nn` in [`GENERATOR-BOARD.md`](../boards/generator-b/GENERATOR-BOARD.md),
  each naming the issue that argued for it. The open items are that file's
  §5.
- What each board is, its status, its filed exports and its bench sessions:
  [board A](../boards/controller-a/README.md) and
  [board B](../boards/generator-b/README.md).
- The system design, what decides, what persists, what fails safe and how:
  [`ARCHITECTURE.md`](https://github.com/origin89hq/firmware/blob/main/docs/ARCHITECTURE.md)
  in origin89hq/firmware.
- The wire between the two processors and to every client:
  [KM43](https://github.com/origin89hq/km43).

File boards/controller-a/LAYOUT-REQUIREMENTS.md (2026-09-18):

# Origin89 — PCB layout requirements

For an external layout house. This document says what the boards must satisfy and
**why**, because a rule with no reason attached is the first thing a layout tool
optimises away.

The reasoning behind the circuits is in [`docs/DESIGN.md`](../../docs/DESIGN.md).
This file does not repeat it; it extracts only what constrains placement and
routing.

Rules added or changed for revision B name the issue that argued for them, and
the issue holds the evidence. Where a rule changed, what revision A was built
with is stated beside it, so an export can be checked against either.

Requirements are numbered `A-nn` for the controller; the generator board's
`B-nn` live in [GENERATOR-BOARD.md](../generator-b/GENERATOR-BOARD.md) (§4). Reply against
the numbers. **Any requirement that cannot be met must be
raised before routing starts, not reported afterwards.** Several trade against
each other, and we would rather choose than be told.

---

## 1. Two boards, and why the split exists

A controller that starts a generator at an unattended site four hours from a
road. It sits in a 3D-printed plastic enclosure in an electrical room, beside an inverter,
next to a running generator, through a Canadian winter. Nobody is watching it
fail.

| | Board | Carries |
|---|---|---|
| **A** | **Controller** | STM32G0B1, ESP32-C6 module, three RS-485 channels, CAN, two VE.Direct ports, 1-Wire, FRAM, NOR, power |
| **B** | **Generator** | Two series relays, the hardware run-enable watchdog, the field wiring to the genset |

**The split is a safety decision, not a packaging one.** The run-enable watchdog
lives on board B with the relays. The link between the boards carries only
"please run", so every way it can fail (connector backed out, cable pulled,
cold joint at −30 °C) stops the watchdog being fed and **opens the contact**. A
lost link is the safe state by construction. On one board the identical fault is
a cracked joint that is silent.

The second reason is surge. 60 ft of 18/2 runs to a generator in the garage and
is the dirtiest thing touching this design. On its own board that energy never
enters the board carrying the MCU, three RS-485 channels and CAN.

---

## 2. Deliverables, both boards

| | |
|---|---|
| Source document | EasyEDA Pro project, editable |
| Gerber | RS-274X, complete |
| BOM | With LCSC part numbers |
| Pick & place | Board A, top and bottom |
| Mechanical drawing | DXF: outline, mounting holes, connector positions |
| Fabrication drawing | PDF, with stackup and **achieved** impedance |
| 3D model | STEP |
| NC drill | Excellon, plated/non-plated separated |
| Assembly drawing | PDF, top and bottom, with designators |
| Netlist | IPC-D-356A, for bare-board electrical test |
| Revision block | Document revision and date on the fabrication drawing, matching the schematic and BOM revision delivered |

We want **all** of these, not the two ticked by default on the quote form. The
DXF and STEP are what let an enclosure be chosen without re-measuring, and the
fabrication PDF is the only place achieved impedance gets written down.

---

## 3. Board A — controller

### Mechanical and stackup

| ID | Requirement | Why |
|---|---|---|
| **A-01** | Outline **100 × 125 mm**, 1.6 mm FR-4 | **The board is the master dimension.** The enclosure is 3D printed around the finished board, so the board is sized for what the layout needs and the box follows. It was 100 × 100 (the cheapest fab tier) until the field band ran out of height: connectors at the edge, bus lamps pinned above them and the MCU keep-out above that left **~15 mm of usable band**, while each bus needs a TVS, a transceiver, a jumper and two bias resistors, about **13.4 mm of bodies before clearances**. Past that point every constraint added there only moved the violation somewhere else; one placement bought unambiguous termination jumpers by pushing the RS485-3 surge clamp **17.7 mm** from its own connector, which is a worse board. The extra 25 mm is all field band. One price tier, not a redesign |
| **A-02** | Four **M3** holes, 3.2 mm finished drill, **3.2 mm keep-out radius** measured from the hole centre and applying to **all copper layers and both silkscreens**, centres **4 mm** in from each board edge (**±46, ±58.5 mm** on the 100 × 125 outline) | Nylon standoffs, not brass. Brass under a board with 24 AWG field wiring nearby is a short waiting to happen |
| **A-03** | Mounting holes on **no net**: no plane, no stitching | The enclosure is **plastic**, so there is no chassis to bond to and nothing a standoff could usefully connect. Site earth exists (off-grid systems bond DC-negative to a rod) but that bond is made **once, elsewhere in the system**. A second bond here would create a ground loop through 60 ft of field wiring, which is an antenna for exactly the surge this board is protected against |
| **A-04** | **4 layer.** L1 signal, **L2 solid ground**, L3 power, L4 signal | L2 must be an uninterrupted reference under every differential pair |
| **A-05** | **Route every controlled-impedance pair on L1 only**, and allow **no split, slot or void in the Layer 2 ground plane beneath any differential pair or either crystal**. A pair routed on L4 references the *split power* plane L3 and is not controlled impedance | A return path that detours around a split radiates, and turns a working bench board into an intermittent field board. If unavoidable, ask. Do not route across it |
| **A-06** | All **field** wiring on one edge: 12 V in, the three RS-485 buses (one of them 4-pin, `A-37`), CAN, 1-Wire, the selector. One gland plate, one loom, one direction of pull | Measured on rev A: 79.4 mm of connectors against 96 mm of usable edge, so it fits. It only fits because the six signal connectors are **3.5 mm pitch**; at 5.08 mm they need 103.4 mm and the requirement becomes unbuildable at this board size. The 4-pin port adds 3.5 mm: one fits in what `A-06c` measures, three do not (#34) |
| **A-06b** | The short in-enclosure leads (VE.Direct `CN6`/`CN7`, the board-to-board plug `CN9` and the second 1-Wire landing `CN11`) go on the **right** edge, and must not cross the field edge | These are patch leads to gear in the same box, not part of the field loom. Putting them on the field edge would push it past 130 mm and force a larger board for no benefit |
| **A-06c** | The **left edge is the sense and control column**: selector (`CN10`), start-battery sense (`CN12`), SWD (`H1`), tank sender (`CN13`), top to bottom. Rev A also had the RTC cell connector (`CN14`) here; rev B moves it inboard (`A-25`) | **The bottom edge is full.** Six bus connectors use 79.4 mm of the 85.6 mm of clear edge between the corner mounting-hole keep-outs on rev A, 82.9 mm once one RS-485 port is 4-pin; a seventh does not fit. That number is measured. Splitting heavy comms/power one way and thin sense wiring the other is also how a panel gets wired |
| **A-07** | ENIG lead-free, green mask, white silkscreen | Flat pads for the LQFP-64 at 0.5 mm pitch; legible to somebody with a headlamp |

### Impedance

| ID | Net | Target |
|---|---|---|
| **A-08** | `CANH`/`CANL` | **120 Ω** differential ±10 %. ISO 11898 interconnect is a nominally 120 Ω cable terminated 120 Ω at each end, and `R13` on this board is 120 Ω; a 100 Ω trace target would contradict both |
| **A-09** | `RS485_1/2/3_A` / `_B` | **120 Ω** differential ±10 %, or as close as the stackup allows; **report the achieved figure** |
| **A-10** | Both pairs | Coupled the whole run, length-matched within 5 mm, no stubs, and on L1 only per `A-05` |

### Placement

| ID | Requirement | Why |
|---|---|---|
| **A-11** | **TVS at the connector**, before the signal reaches anything else | A TVS downstream of the part it protects protects nothing. The surge has already been through the transceiver |
| **A-11c** | **Verify every 3-pin SOT-23 protection device's land pattern against its datasheet before fabrication.** `D4`/`D5`/`D6` (SM712) and `D7` (PESD1CAN) all have the **common on pin 3**, not the middle pin | Neither library symbol names its pins, so a wrong assumption produces a netlist that passes every connectivity check and protects nothing. Both parts were initially wired with pin 2 to ground. Found by reading the electrical tables, which reference every parameter "pin 1 to 3 and 2 to 3" |
| **A-11b** | **Every field TVS returns to `CN1`'s ground pin by a short, wide, low-inductance path**: multiple stitching vias at each TVS ground pad, and the return must **not** traverse the Layer 2 ground beneath `U7`, either crystal, or any sense divider | "At the connector" alone does not say where the energy *goes*. The enclosure is plastic and there is no chassis, so surge leaves only via the 12 V negative to the bank, which is bonded to earth once elsewhere in the system. A TVS that clamps correctly but dumps its current through the plane under the MCU has moved the problem |
| **A-11d** | Every protection part is one whose surge and ESD ratings **its maker publishes**, and the BOM notes the datasheet revision the rating was read from | Rev A's `D1` (SMBJ18A, OTW) is served only a Taisko datasheet, and `D7` (PESD1CAN, DOWO) has a datasheet that gives two different ESD ratings for the same part. A rating nobody can source is a rating the product cannot claim (#42) |
| **A-12** | Each of the **four** buses (RS-485 ×3 and CAN) is **one tight cluster**: connector + TVS + transceiver + termination resistor + termination jumper + activity LED. **≤ 14 mm pad to pad**, connector A-pin to transceiver A-pin. This one is stated pad-to-pad, not centre-to-centre like the rest of the document, because the number *is* the A/B trace length. **Do not pool parts by type** | A parts-bin layout is tidy and electrically wrong. **Delivered at ≤ 14 mm pad-to-pad on all four buses** (14.2–16.7 mm centre-to-centre, the spread being connector and SOIC body length). 11 mm was attempted to bring the centre-to-centre figure under 15 and the solver could not hold it. Four hard pairs came back at 11.2–13.8 mm, so the limit is set where it actually places. The surge clamp is the part that must be at the terminal: **`D4`–`D7` sit 5.4–8.7 mm from their connectors**. Rev B's 4-pin `CN4` (`A-37`) widens that cluster by 3.5 mm; the pad-to-pad limit is unchanged |
| **A-13** | Each 120 Ω terminator (`R7`, `R9`, `R11`, `R13`) is in series with a **2-pin header and shunt** (`JP1`–`JP4`). Place each header at its own bus cluster, **reachable and readable with the board installed**, silkscreened with the bus name and which state is terminated. Default shipped state: **fitted** | Whether this board terminates depends on where it sits on the bus, and that is decided by whoever pulls the wire at install, not at assembly. A shunt is finger-operable and puts no sliding contact in the bus path, unlike a DIP switch, whose intermittent contact would make termination flicker. **Correction to an earlier draft:** a third 120 Ω terminator takes the parallel load from 60 Ω to 40 Ω. It does not "halve the swing", it loads the driver by half again |
| **A-13b** | Fail-safe bias `R49`/`R50`, `R51`/`R52`, `R53`/`R54` (560 Ω on rev A, raised for rev B by `A-13c`) placed **inside their own bus cluster**, close to the transceiver, not scattered to the power area | **The MAX13487E datasheet makes these mandatory:** *"The pullup and pulldown resistors on the A and B lines are required for proper operation of the device… they function to hold the bus in the high state (A−B > 200 mV) following a low-to-high transition."* The AutoDirection state machine takes the current A−B state as an input, so without bias its direction control runs on an undefined input. The receiver threshold is ±200 mV, so an unbiased idle bus is indeterminate. 560 Ω gives 254 mV idle with both ends terminated (60 Ω), 485 mV with one |
| **A-13c** | Rev B bias sized so the idle bus stays **above the receiver's 200 mV band with three terminators** (40 Ω): about **390 Ω**, which gives 357 mV with two terminators and 244 mV with three at 5 V, 232 mV at `V5`'s 4.75 V minimum. Settle the value on a real cable before ordering, against the bias of the other devices on the site's buses | 560 Ω leaves 254 mV with two terminators and 172 mV with three, inside the MAX13487E's undefined band, and a mid-bus board with its jumper still fitted is the three-terminator case. Two terminators keep only 40–50 mV of margin against noise on a long cable (#26). The silkscreened jumper state of `A-32` is the other half of the defence |
| **A-14** | `LED1`–`LED3` (RS-485) and `LED6` (CAN) visible from the connector edge, each labelled with its bus. Rev B drives every indicator at roughly **0.2–0.5 mA**, the resistor values settled by eye on the rev A bench | They sit on the receiver output, so they show **RX activity**, which is the useful signal: it means something *else* on the bus is talking. Somebody at the panel learns the bus is alive without a laptop. Delivered aligned to within 0.1 mm of their own connector in x. Rev A's parts at about 2 mA are far brighter than an indicator needs in an electrical room, and the transceivers switch the four bus LEDs, so firmware cannot dim them (#35) |
| **A-15** | **`ESP32-C6-WROOM-1-N8`** (Espressif, datasheet v1.x; confirm revision against the shipped part). **No copper on ANY layer** under the module's declared antenna keep-out, and the **antenna at or past the board edge, or the board cut away on both sides of and below it** as Espressif's ESP32-C6 layout guide describes. Espressif additionally require **≥ 15 mm clearance from the antenna to any material inside the finished enclosure**, and end-product range testing; a copper void alone is not sufficient | A module antenna over a ground plane is a module that does not connect, discovered after fabrication. The 15 mm is an enclosure constraint, so it lands on the 3D-printed box as much as on the PCB. Rev A's antenna end sits about 4 mm inside the edge with no cutout; the copper void itself is clean, and the range cost is unmeasured (#16) |
| **A-16** | Keep the antenna end away from every switching regulator, rev B's front-end buck (`A-20e`) included | |
| **A-17** | `X1` within **5 mm** of `U7` pins 10/11 (`OSC_IN`/`OSC_OUT`); `C29`/`C30` within 3 mm either side; **both cap grounds joined to each other first, then one short run to pin 9** (`VSS`, the adjacent pin); no track under `X1` on any layer, unbroken ground on L2 beneath; **≥ 10 mm from the switching inductors `L1`/`L2` and the switch nodes `SW_5V`/`SW_3V3`** | The link runs at 921600 and the clock is what makes that rate honest. **Met in the delivered placement, centre-to-centre: 16.6 mm from inductor `L1`, 49.6 mm from inductor `L2`.** All distances in this document are centre-to-centre unless stated. It took a placement keep-out over the MCU area to get there. Clearance rules alone lost three times to the `V3V3` ratsnest, which drags the 3.3 V buck centre-board because that rail fans out to the MCU, ESP32, FRAM and NOR. **A keep-out anchored at the board centre is not by itself enough, and believing it was cost two more respins of the placement.** The region is anchored at the centre but it does not *hold* the MCU there. The clock block is allowed anywhere inside it, including hard against its own boundary, with a converter legally sitting immediately on the other side. `L1` came to rest **4.49 mm** from `X1` with a 50 mm-wide exclusion nominally protecting it. The rule holds because `U7` is pinned to the board centre. The crystal is tied within 7 mm of `U7`, so it cannot travel more than ~12 mm out, and the 25 mm half-width then guarantees the separation no matter what else moves. **Do not undo it while routing.** Nothing in the netlist or the Gerbers records that this separation is deliberate, so moving `L2` inboard to shorten a trace kills the requirement silently. The victim is a high-impedance node swinging a few hundred mV; the aggressor slams 12 V in nanoseconds at 570 kHz a few cm away. The cost is a pulled clock rather than a dead board. A UART has no clock line, so at 921600 the two ends must agree within a couple of percent across a whole byte. It works on a bench at 20 °C and drops frames in January. If 10 mm from both inductors is ever impossible, prioritise distance from `L2`: it shares a rail with the MCU, so its noise has the shorter path into the ground the oscillator references |
| **A-18** | For **each** TPS54331 (`U1` with `C3`/`L1`/`D3`, `U2` with `C31`/`L2`/`D8`), per the TI datasheet layout section, and for the front-end buck of `A-20e` per its own datasheet: (a) minimise the **input-capacitor → VIN → GND → catch-diode** loop area (the high di/dt loop); (b) place the catch diode and the inductor **immediately at the PH pin**; (c) keep **PH/switch-node copper as small as the current allows** (it is the dv/dt aggressor, not a heatsink); (d) route neither loop's return under a bus pair, either crystal, or any sense divider | "Input cap, inductor, diode in a tight loop" in an earlier draft was electrically imprecise. The inductor is not in the fast loop, the catch diode is |
| **A-19** | `C24`/`C25` within 5 mm of the ESP32 supply pin | It draws 382 mA in bursts |
| **A-26** | **1-Wire protection in order along the path**: the `OW_VCC` limit of `A-24` upstream on `V3V3`; `D9` (ESD clamp) **at `CN8`**, ahead of anything else; `R41` between the field node and `PC4`, **raised on rev B from 100 Ω to a few hundred ohms with the 1-Wire timing still met, and a clamp to `V3V3` and GND at the MCU side whose clamp voltage stays under `PC4`'s VDD + 4 V rating** | Same rule as `A-11` and for the same reason. The clamp behind the series resistor protects the resistor, not the MCU. These probes hang outdoors and in a battery box on cable nobody will inspect again. `D9` is an ESD diode whose clamp reaches 26 V, and 100 Ω in front of a pin rated 7.3 V limits little; `PC4` is FT with no positive injection allowed, so there is no internal clamp to lean on (#31) |
| **A-27** | `R46` (150 Ω, 4-20 mA sense) **at `CN13`**, its return short and not shared with the switching loops | That resistor *is* the measurement. Loop return current wandering through the board becomes a fuel reading that drifts with load |
| **A-28** | `X2` (32.768 kHz) and `C41`/`C42` tight to `U7` pins 4/5, guarded, unbroken ground beneath, **≥ 10 mm from the switching inductors `L1`/`L2` and the switch nodes `SW_5V`/`SW_3V3`** | Same aggressor as `A-17`, and an LSE is *more* fragile than the HSE: lower amplitude, higher impedance, and it has to keep time for years, not just clock a UART |
| **A-29** | `R44`/`R45` with `C39` at `CN12`, and `R42`/`R43` with `C38` beside them off `V_BANK`, ahead of the front-end buck so the house reading is the bank and not the regulated rail (`A-20`), stay **in the left-edge sense column** with `R46`/`C40` (`A-27`); each divider's ground returns to the plane at the divider, and every `AIN_*` trace runs on L1 over unbroken L2 ground, **never through or over either switching loop**. `A-11b` and `A-18`(d) already keep aggressors away from the dividers, and this extends the same protection to the traces, which now cross the board | An earlier draft wanted these dividers at the ADC pins, and the placement that went to routing has them at the sense column instead. Accepted rather than reworked, for two reasons: the left edge is where the sense wiring lands (`A-06c`), and the divided node is not bare; 100 nF across the bottom resistor holds it low-impedance above ~175 Hz (9.1 kΩ Thevenin) while the channels are read at about 1 Hz. What that capacitor cannot do is shunt pickup collected along the trace *after* it, so the trace route is now the requirement: a divider is still a high-impedance node, noise on it is indistinguishable from a real change in battery voltage, and this board decides whether to start a generator on that number |
| **A-30** | The compensation network sits **on the COMP pin**: `R4`/`C9`/`C45` at `U1` pin 6, `R38`/`C37`/`C46` at `U2` pin 6, with `C45`/`C46` the closest of the three to the pin, and their ground returned to the IC's own ground pin rather than into the switching loop | `COMP` is the error amplifier's output and the highest-impedance node on either converter. `C45`/`C46` (100 pF) exist to shunt switching pickup to ground **at the pin**; on the far end of a 20 mm trace they filter nothing and the trace itself becomes the antenna. The values were recomputed against the real filter (see [the compensation section](../../docs/DESIGN.md#the-bucks-compensation-recomputed) of `docs/DESIGN.md`), and a loop with 74° of phase margin on paper is still a ringing rail if this node picks up the switch node |
| **A-32** | Each termination jumper sits **unambiguously above its own connector** (`JP1`↔`CN2`, `JP2`↔`CN3`, `JP3`↔`CN4`, `JP4`↔`CN5`), closer to it than to any other connector by a clear margin, and **each is silkscreened with the bus name, not just its designator** (`TERM RS485-1`, not `JP1`) | The first placement put the whole jumper row about 7 mm left of where it belonged, which left each one roughly equidistant between two buses: `JP2` measured 11.1 mm to `CN2` and 11.8 mm to `CN3`, so three of the four were physically nearest a bus they do not terminate, and `JP1`'s nearest connector was `CN1`, the 12 V inlet. Somebody terminating the EPEver bus reaches for the jumper above `CN2`, fits `JP2`, and terminates the PZEM DC bus instead. **Nothing reports this.** Both buses still talk on a bench; the unterminated one starts throwing CRC errors over 60 ft on a cold night, which is a four-hour drive to diagnose. The LEDs were already immune because they are pinned to their connector's centreline (`A-14`); the jumpers were only softly attracted, and soft lost |
| **A-31** | `C44` (1 µF) within 3 mm of `U7` pin 7 (`VREF+`), **and on rev B a 100 nF at pin 7 and another at pin 8 (`VDD/VDDA`), each as close as the package allows, on the underside beneath the pins if the top is crowded, with the 4.7 µF near pin 8** | `VREF+` is the ADC's reference, and on this package it is a separate pin from `VDD/VDDA` (pin 8) even though both are on `V3V3`. Three of those ADC channels (house bank, start bank, tank level) are inputs to the decision to start a generator. Reference noise does not look like noise in the result; it looks like the battery moved. DS13560 figure 15 asks for 100 nF plus 4.7 µF on VDD/VDDA and 100 nF plus 1 µF on VREF+, placed as close as possible to the pins; on rev A the nearest 100 nF is 6.4 mm away, and how much that contributes to the rail-switch faults of item 8 is not known (#32) |
| **A-33** | **The silkscreen names every connector and its pins in pin order, every jumper with its bus and terminated state, every LED with its function, the debug header's pins, the button, and the board name, revision and date**, with a pin-1 or polarity mark on every connector. The label list lives in `gerber-rules.json` and `tools/validate_silkscreen.py` checks the exported `board.dxf` against it as whole strings, so each label is one text object (`TERM RS485-1` on one line, not two). That check proves presence, not position: that each label sits at its connector with the pins in order is checked by eye on the assembly drawing until the check learns positions from the pick-and-place (#49). The enclosure's port strips follow the board with the rev B export (#20, #34) | Rev A's silkscreen carries 133 designators and nothing else, so on the bare board nothing says what a connector, pin, jumper or LED is for, and a swapped A and B, a reversed start-battery lead or a jumper in the wrong state has nothing to catch it. Board B already writes `CN9`'s pin order on its silkscreen (`B-09`); board A's side does not (#12) |
| **A-34** | **`CN9`'s logic lines are protected at the connector on board A**: a series resistor and a TVS on each of `RUN`, `KICK` and `FEEDBACK` at `CN9`, with a clamp at the MCU side whose clamp voltage stays under the pins' VDD + 4 V rating as in `A-26` and `A-36`, since a surge TVS alone clamps well above it; a pull-down on `RUN` and on `KICK` strong enough to hold board B's `Q2` off against the STM32's 25 kΩ internal pull-up (4.7 kΩ gives about 0.5 V), **placed on the MCU side of the series resistor** so the pin still drives 3.3 V and the cable sees about 3.27 V through 1 kΩ against board B's 100 kΩ; on the cable side the same 4.7 kΩ would leave 2.7 V with 1 kΩ in series and 2.2 V with 2.2 kΩ, at or under the 74HC123's VIH of about 2.3 V at 3.3 V. `FEEDBACK` carries the firmware's internal pull-up (`B-09b`) and gets no pull-down; through 1 kΩ it reads about 0.13 V low with both contacts closed. All three on MCU pins that ST's system bootloader does **not** configure (AN2606 table 95 for the STM32G0B1). `CN9`'s pin order stays `B-09`'s. Design this with board B's `B-03` and its rev B milestone: same cable, same nets | On rev A `PD0`, `PD1` and `PD2` run straight to the cable, and unplugging board B with board A running cost the RTC about 5 s in one step, a connector breaking ground before 12 V being the likely path (#8). Worse, `PD0`/`PD1` are the bootloader's FDCAN1 pins: with an empty flash, which every board has before programming and after an interrupted update, the bootloader pulls `RUN` to 2.1–2.6 V, above board B's gate threshold, and can pulse `KICK`, so the generator's start contact can close with no firmware running. Board B's monostable guards against a stuck controller, not a bootloader that looks like one (#30). The bootloader also configures other rev A nets, `PA2`/`PA3` (USART2, on RS485_1) and `PB6`/`PB7` (I2C1, on the ESP32 link) among the candidates to confirm in table 95, which is why the check is against the table and not the three nets alone |
| **A-35** | **`CN13` is a connector that cannot mate with the 3.5 mm logic sockets** (a different pitch or pin count, or a keyed header), with a TVS at the connector, its loop supply from the rail in `A-20d`, `R46` at the connector as `A-27` and rated for the pin 1 to pin 2 fault, and `R47` raised with a clamp on `AIN_TANK` at the MCU side. Record the minimum sender supply the board supports beside `A-20d` | Rev A's tank plug fits `CN2`–`CN5`, `CN8`, `CN10` and `CN11`: in `CN10` it puts 12 V on `PB12`, in `CN8` or `CN11` on `OW_VCC` and through `F2` onto the 3.3 V rail. A shorted or miswired sender puts 12 V across `R46`, about 1 W in a ⅛ W part, and `R47` then pulls `PB2` past its 7.3 V limit (#24) |
| **A-36** | **`CN10`'s `SEL_AUTO` and `SEL_MANUAL` reach `PB12`/`PB15` through a series resistor of about 1 kΩ and a clamp to `V3V3` and GND whose clamp voltage stays under the pins' VDD + 4 V rating**, with ESD protection at `CN10` | Rev A has only the 10 kΩ pull-ups. The pins are FT type with no positive injection allowed, and the selector's cable is field wiring (#31) |
| **A-37** | **One RS-485 port, `CN4`, is 4-pin: `A`, `B`, `GND`, `5V`**, pins 1–3 in the same order as `CN2` and `CN3`, the 5 V pin fed as `A-20c` with an ESD clamp or TVS on it at the connector, and labelled per `A-33`. Check what a 3-pin plug does in the 4-pin socket when pushed in at either end | The PZEM-017's RS-485 side is passive and wants an external 5 V at more than 100 mA over the bus cable; rev A read one on `CN4` at 9600 8N2 as soon as it had 5 V from elsewhere, 119 of 120 polls (#34). Keeping `A`, `B`, `GND` on pins 1–3 keeps one plug order across all three ports. The alternative, all three ports 4-pin at 2.5 mm pitch, also stops those plugs mating with the 3.5 mm sockets and stays open if the part's wire range takes the field cable |
| **A-38** | **VE.Direct ports listen on pin 2**, the producer's TX, with pin 3 left for a controller TX; **a digital isolator per port** whose Victron side is powered from the port's pin 4 within Victron's limit for that pin, 10 mA average and 20 mA for 5 ms bursts, and works at both levels Victron's products drive, 5 V on every MPPT and 3.3 V on the BMV, RS and inverter families; an isolator whose board-side output defaults high while its Victron side is unpowered, so an unplugged port reads idle by the part's own fail-safe and not by a pull-up alone; ESD protection at the connector; pins labelled `RX` and `TX` from the board's own side, as Victron's table reads them, so the port takes Victron's crossed cable | Rev A listens on pin 3, its own TX position, so it works only with a straight cable that joins pin 3 to pin 3, and the silkscreen should not invite that cable back. Victron's MPPTs drive 5 V, which exceeds the FT pins' limit whenever the internal pull-up is on or board A is off, and Victron's FAQ asks for galvanic isolation because the product side has little protection of its own; the same FAQ's port table gives the 10 mA limit and the two logic levels (#27) |
| **A-39** | **ESP32 module lines and straps**: about 1 kΩ in series on `ESP_TX`, `ESP_RTS`, `ESP_EN` and `ESP_BOOT`; pull-ups on IO8 and IO9 to `V3V3_ESP`, not `V3V3` (4.7 kΩ worked on the bench for IO8; confirm against the module datasheet's strapping table), **each at least four times the series resistor in front of the STM32 pin that drives the strap, so the STM32 holds IO9 under the module's VIL of 0.25 × VDD**: 1 kΩ against 4.7 kΩ leaves 0.58 V under the 0.825 V limit, 1 kΩ against 2.2 kΩ leaves 1.03 V and does not; EN held by a voltage supervisor **monitoring `V3V3_ESP`, not `V3V3`**, with an open-drain output, the RC kept, and `PC2` still able to hold EN low, its threshold fixed only after `V3V3_ESP` has been measured under a Wi-Fi burst through the new switch on the rev A rework (item 9 of §5), since Espressif's suggested 3.0 V sits only 0.29–0.34 V under the 3.29–3.34 V the bench saw on `V3V3`; IO12, IO13 and GND on pads as a USB recovery path. The link pins stay as rev A built them: `PB6` to RXD0, TXD0 to `PB7`, `PB3` to IO4, IO5 to `PB4` | Rev A's IO8 is unconnected, so the STM32 cannot enter the serial download mode and a blank module needs a wire held on the pad (#6). The STM32's lines go straight to the module, so a pin driven high with the rail off back-powers it through its input protection and the recovery power cycle may not reset it (#17). Espressif's checklist says the EN RC alone is not enough when the rail is power-cycled, which is what recovery does (#14), and a supervisor on `V3V3` would never hold EN low while the module's own rail is down. The link stays on the module's UART0 and the firmware follows the board (#13) |
| **A-40** | **The debug header is 6-pin in ST's ST-LINK order: `VDD`, `SWCLK`, `GND`, `SWDIO`, `NRST`, `SWO`**, and `C23` sits next to `U7` pin 12. The `SWO` position stays in place but unconnected, silkscreened `NC` | Rev A's `H1` carries no NRST, so a probe cannot connect under reset, and firmware that reconfigures `PA13`/`PA14`, sleeps, or faults early locks it out, with no bootloader way back because `BOOT0` shares `PA14`. Rev A's only recovery is a wire to `C23`'s pad, 7.8 mm from the pin (#29). The Nucleo probe then plugs straight in. The G0's Cortex-M0+ has no trace output, so a pin labelled `SWO` would promise what the part cannot give |
| **A-41** | A **10–100 kΩ pull-up to 3.3 V on each `RS485_x_TX` net**, inside its bus cluster | Each MAX13487E drives its bus low whenever DI is low, and its own hot-swap pull-up works only at the transceiver's power-up. During any STM32 reset every I/O is an analogue input, so DI floats until firmware sets up the UART. On rev A all three RX lamps stayed lit for minutes under an image that never configured those UARTs, which is three buses held low (#28) |
| **A-42** | **One tactile switch, read by the STM32**: a spare GPIO to GND with a pull-up to `V3V3` (10 kΩ or the pin's internal one), a series resistor and ESD protection as `A-36`, the pin's I/O type confirmed in DS13560 and `PA11`/`PA12` left untouched; placed where the enclosure can expose it recessed or behind a pinhole; labelled per `A-33` with a name that does not read as reset. **The firmware defines the gestures, at least three distinct ones**; the board fixes none of them. No power function | The only local input on rev A is the selector, and a full event-ring dump has to be asked for by holding both selector inputs low at power-up. `docs/PROTOCOL.md` in origin89hq/km43 asks two things of this button, and the product adds the hold: P-066 gates enrolment on a physical press that opens a pairing window on any transport, P-117 arms the floor override only by a press pattern distinguishable from that press and from the factory-reset hold, and the hold itself is product-local. The STM32 owns all three because it holds the ESP32's rail and both records (#11). A power button would only add a way to switch the interlock off by mistake, and a recessed button on a wall people touch is an ESD entry like the selector |

### Power

| ID | Net | V | A | Note |
|---|---|---|---|---|
| **A-20** | `V_IN_RAW` / `V_BANK` | 12 or 24 | 2.0 | **Rev B runs from a 12 V or a 24 V bank, and everything past the front end runs from a regulated 12 V** (`A-20e`). State the maximum continuous input the board supports, the highest voltage a 24 V bank's charger applies with equalisation included, about 29 V and up, and build the chain from it, in this order from `CN1`: `F1`; a **bidirectional** TVS at the connector (`A-11`) with its standoff above that maximum (a 33 V-class part clamps near 53 V); then reverse-polarity protection the TVS cannot bypass, a P-FET or an ideal-diode controller whose drain-source rating exceeds the TVS clamp and whose gate is clamped within its gate-source rating at the maximum input, as rev A does with `D2` (BZT52C10) and `R1` on `Q1`'s gate; then the front-end buck of `A-20e`, the only converter that sees the bank, with a **60 V-class** input rating so the clamp lands under it; every capacitor on `V_BANK` and `F1` rated for the maximum input. The house-bank divider `R42`/`R43` (`A-29`) reads `V_BANK`, not the regulated rail. Trace ≥ 1.5 mm. A bank wired by hand in the field will be reversed once. Rev A's unidirectional `D1` sat ahead of `Q1`, so a reversed bank conducted through it, its clamp landed within 1 V of the converters' 30 V limit, and `Q1`'s 30 V rating has no margin over a reversed 24 V bank; a unidirectional TVS anywhere ahead of the reverse element reproduces that path, and a TVS behind it leaves the reversed bank and every negative transient on the FET alone (#15, #20). Rev A was built for 12 V only, with `V12` the bank itself |
| **A-20e** | `V12` | 12 | 1.5 | **The regulated 12 V rail, from one 60 V-class buck on `V_BANK`.** It feeds `U1` and `U2`, which stay rev A's TPS54331 parts and now see 12 V at most, `CN9` pin 1 (`A-20b`), the tank loop boost (`A-20d`) and any later accessory output (item 10), each output behind its own limiter. Below 12 V the buck passes the bank through, about 10.2 V at a discharged 12 V bank, which every consumer tolerates: the TPS54331 regulates from 3.5 V and board B's coils pull in at 9 V. Budget: the 5 V and 3.3 V rails at full load draw about 0.9 A from 12 V, `CN9` 0.1 A, the loop 0.05 A. `A-18`'s layout rules and the `A-16`, `A-17` and `A-28` distances apply to this converter's inductor and switch node as they do to `L1`/`L2`. Why here and not on board B: the bank voltage then reaches only the front end and this one converter; board B stays a 12 V board on any bank, which fixes its coil overvoltage (#21) and keeps a switcher out of its safety chain (#33); and one new part class replaces three. A failed buck takes the controller down as a blown `F1` does, the safe direction |
| **A-20b** | `CN9` pin 1 | 12 | 0.1 | Feeds board B's two relay coils, about 100 mA at 12 V, over a cable that leaves the controller's box, **from the regulated rail of `A-20e` through its own active current limit with its fault readable by the MCU**, sized for that load with headroom, about 250 mA, not a PTC alone: `F1` at the inlet is otherwise the only device between the bank and a pinched cable, and tripping it loses the controller and the generator interlock it feeds (#47). `FEEDBACK` high because the coil supply is in fault is a different diagnosis from `FEEDBACK` high because board B opened the contact, and firmware can only name it if the flag exists. State with the part whether the limit latches or retries after the inrush into board B's input capacitance at plug-in, since firmware depends on which. The pin carries the `A-20e` rail, **12 V nominal and not below 10 V at `CN9`**: a 12 V bank discharged to 10.5 V passes through the buck at about 10.2 V, the limiter drops tens of millivolts at 100 mA, and the under-3 m cable of 22 AWG or heavier drops under 50 mV; board B's coils pull in at 9 V, 75 % of rated, so the envelope clears them on any bank. `B-09` states the same envelope, its `+12V` label stays true, and board B has no bank-voltage work (#20, #33) |
| **A-20c** | `CN4` pin 4 | 5 | 0.3 | The 5 V pin of `A-37`, from `V5` through an active current limit **with its fault readable by the MCU**, sized for a few meters at more than 100 mA each, so a shorted meter cable cannot sag `V5`. A meter bus that is silent because its 5 V tripped is a different fault from a meter that is not answering, and the log should say which. Inside `A-21`'s budget, or raise it (#34) |
| **A-20d** | Tank loop supply | 24 | 0.025 | A regulated, current-limited rail for a 2-wire 4–20 mA sender on `CN13`, boosted from the regulated 12 V of `A-20e`, so it is the same on either bank. From rev A's `V12` the sender saw the bank minus 3 V across `R46` at 20 mA, about 9 V on a 12 V bank and less as it discharges, under the 11–12 V minimum common transmitters need, so the reading was wrong near full scale (#36). Write here the minimum sender supply it supports once the parts are chosen |
| **A-21** | `V5` | 5 | 1.5 | RS-485 and CAN transceivers |
| **A-22** | `V3V3` | 3.3 | 0.8 | Logic + ESP32. Size for burst, not average |
| **A-23** | `V3V3_ESP` | 3.3 | 0.5 | Switched sub-rail, gated by the MCU so a wedged comms processor is recoverable without a drive. **Rev B: the switch is slew-limited, about 1 ms or slower, discharges the rail while it is off, and defaults on**: its enable is pulled up so the rail is up with `PC5` high-impedance, and `PC5` drives low to cut it (item 8 of §5, #5, #14). The controller takes ownership of the rail once it has booted and applies its policy from there: the recovery ladder's cuts (L-111 and L-112 in `docs/protocol/LINK.md` of origin89hq/km43) and a bank-voltage threshold below which it keeps the radio off, so "radio off" is always a logged decision by running firmware and never a reset's side effect. Rev A's `Q2` switched it hard and defaulted off, which nobody chose: `PC5` is high-impedance through every reset, `Q3` is off, `R19` holds `Q2` off, and `C24` cannot hold 60 mA for the milliseconds until firmware drives `PC5` again, so every STM32 reset reboots the ESP32, costs a Wi-Fi association, and is one more switch-on of the kind item 8 is open on; a crash loop at the 8 s watchdog is 450 rail cycles an hour against L-112's three deliberate ones. Cold power-on brings the rail up with `V3V3` through the switch's slew, so there is no separate inrush event at boot. The one case arguing the other way, a brown-out recovery on a weak bank where the module's first Wi-Fi burst comes before the policy runs, is bounded to under a second at about 1.3 W and is measured under item 9 rather than argued. L-114's rationale is being rewritten onto this argument (origin89hq/firmware#3). Two consequences to carry: a blank or crash-looping STM32 now leaves the radio powered until firmware runs, so the recovery ladder's cuts exist only in running firmware; and a tool that reads `PC5` must map high-impedance to on for rev B, where o89-dev reads it as not driven, which was off on rev A |
| **A-24** | `OW_VCC` | 3.3 | 0.1 | **Leaves the board on field cable** to DS18B20 probes outdoors and in the battery box. Rev A feeds it through `F2`, a 100 mA PTC; **rev B feeds it through a current-limited load switch, tens of mA, with its fault readable by the MCU, and clamps the net**. `F2`'s 0.75 Ω minimum lets a dead short draw 4.4 A from `V3V3`, more than `U2` delivers, so the rail sags before `F2` trips (#25). Without protection a chewed or water-ingressed probe cable shorts 3.3 V and takes the whole controller down: a $3 sensor killing the machine |
| **A-25** | `VBAT_RTC` | 3.3 | <1 mA | RTC backup, OR-ed from `V3V3` and an external cell through `D11`, which stays between the cell and the rail so the cell is never charged. The cell connector sits **inboard** on rev B, a 2-pin type that suits a board-mounted lead such as the JST PH already used for `CN6`/`CN7`; rev A's `CN14` took a slot in the left-edge column it did not need (#10). External to the *board*, not to the box: the cell and its holder live inside the enclosure, so the connector is not field wiring and carries no label on the port strips. Keeps the event log's timeline across a power loss |

---

## 4. Board B — generator

Drawn and routed in-house, so this brief never went out for it. Its rules are
numbered `B-nn` in [GENERATOR-BOARD.md](../generator-b/GENERATOR-BOARD.md), beside the
schematic they constrain and the bench proof they are checked by, and that
list is the only one. A second copy here would be two documents free to
disagree, which they had already begun to do. What this file keeps about
Board B is what a layout house would need: the split in §1, the deliverables
in §2, and items 5 and 6 of §5.

---
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

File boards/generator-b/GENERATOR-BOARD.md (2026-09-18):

# Generator board (Board B)

The board that owns the generator contact. [`docs/DESIGN.md`](../../docs/DESIGN.md#the-generator-interface)
decided what it is and why it is a separate board; this file is what was drawn
from that, the rules the layout has to keep, and what the bench has to prove
on the first boards. The schematic is `Generator / Schematic2` in the
EasyEDA project `origin89-fab`, beside the controller's.

Status: **schematic drawn and verified; PCB placed (80 × 55 mm, 2 layers)
and routed with the seven B-10 test pads, contact nets 1.0 mm wide and held
1.5 mm from every other net by a DRC rule, GND routed as a net under both
pours, DRC empty, CN9 pins and test pads named on the silkscreen; five
boards ordered from JLCPCB, assembled, SMD and through-hole alike. Bench
proof happens on those boards, not on a breadboard.**

**Bench, 2026-09-14: the relays switch, but on these boards both relay chains
use each pole's NC and NO terminals and leave the commons unconnected, so
neither the contact nor `FEEDBACK` can close ([bench log](bench/2026-09-14.md)).
The relay rows and the chains below give Omron's pinout; the copper does not
follow it yet.**
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

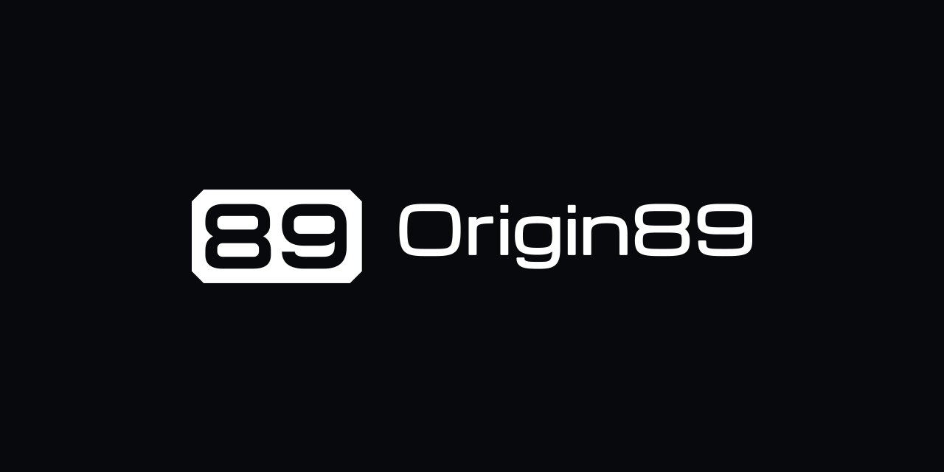
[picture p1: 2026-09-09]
.github/social-preview.png

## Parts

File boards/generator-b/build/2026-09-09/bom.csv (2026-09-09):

No. | Quantity | Comment | Designator | Footprint | Value | Manufacturer Part | Manufacturer | Supplier Part | Supplier
1 | 2 | 100nF | C1,C4 | C0603 | 100nF | CL10B104KB8NNNC | SAMSUNG(三星) | C1591 | LCSC
2 | 2 | 10uF | C2,C3 | C1206 | 10uF | CL31B106KAHNNNE | SAMSUNG(三星) | C14860 | LCSC
3 | 1 | B5P-VH(LF)(SN) | CN9 | CONN-TH_B5P-VH-LF-SN |  | B5P-VH(LF)(SN) | JST | C160318 | LCSC
4 | 1 | KF2EDGR-5.08-2P | CN10 | CONN-TH_2P-P5.08_KF2EDGR-5.08-2P |  | KF2EDGR-5.08-2P | KEFA(科发) | C441204 | LCSC
5 | 3 | SMAJ15A | D1,D2,D3 | SMA_L4.3-W2.6-LS5.1-RD |  | SMAJ15A | Brightking(君耀电子) | C20623846 | LCSC
6 | 2 | 1N4148W | D4,D5 | SOD-123_L2.7-W1.6-LS3.7-RD-1 |  | 1N4148W | YONGYUTAI(永裕泰) | C2892570 | LCSC
7 | 1 | SMBJ30CA | D6 | SMB_L4.5-W3.6-LS5.3-BI |  | SMBJ30CA | BOURNS | C2831484 | LCSC
8 | 1 | BLX-A-B | F1 | FUSE-TH_BLX-A-B |  | BLX-A-B | XFCN(兴飞) | C41371862 | LCSC
9 | 2 | G5V-2-DC12 | K1,K2 | RELAY-TH_G5V-2-12V |  | G5V-2-DC12 | OMRON(欧姆龙) | C28089 | LCSC
10 | 2 | KT-0805G | LED1,LED2 | LED0805-R-RD |  | KT-0805G | KENTO | C2297 | LCSC
11 | 2 | AO3400A | Q1,Q2 | SOT-23-3_L2.9-W1.3-P1.90-LS2.4-BR |  | AO3400A | ChipNobo(无边界) | C42419946 | LCSC
12 | 2 | 100kΩ | R1,R2 | R0603 | 100kΩ | 0603WAF1003T5E | UNI-ROYAL(厚声) | C25803 | LCSC
13 | 1 | 1MΩ | R3 | R0603 | 1MΩ | 0603WAF1004T5E | UNI-ROYAL(厚声) | C22935 | LCSC
14 | 2 | 10kΩ | R5,R6 | R0603 | 10kΩ | 0603WAF1002T5E | UNI-ROYAL(厚声) | C25804 | LCSC
15 | 1 | HT7533-1 | U1 | SOT-89-3_L4.5-W2.5-P1.50-LS4.2-BR |  | HT7533-1 | CBI(创基) | C21714136 | LCSC
16 | 1 | 74HC123D,653 | U2 | SOIC-16_L9.9-W3.9-P1.27-LS6.0-BL |  | 74HC123D,653 | Nexperia(安世) | C5597 | LCSC

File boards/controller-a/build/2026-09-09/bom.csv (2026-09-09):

No. | Quantity | Comment | Designator | Footprint | Value | Manufacturer Part | Manufacturer | Supplier Part | Supplier
1 | 3 | 10uF | C1,C3,C31 | C1206 | 10uF | CL31B106KBHNNNE | SAMSUNG(三星) | C89632 | LCSC
2 | 21 | 100nF | C2,C4,C5,C13,C14,C15,C16,C17,C19,C20,C22,C23,C25,C27,C28,C32,C33,C38,C39,C40,C43 | C0805 | 100nF | CL21B104KBCNNNC | SAMSUNG(三星) | C1711 | LCSC
3 | 7 | 22uF | C6,C7,C11,C21,C24,C34,C35 | C0805 | 22uF | CL21A226MOQNNNE | SAMSUNG(三星) | C98190 | LCSC
4 | 4 | 10nF | C8,C9,C36,C37 | C0805 | 10nF | CL21B103KBANNNC | SAMSUNG(三星) | C1710 | LCSC
5 | 2 | 1uF | C26,C44 | C0805 | 1uF | CL21A105KAFNNNE | SAMSUNG(三星) | C95840 | LCSC
6 | 2 | 30pF | C29,C30 | C0805 | 30pF | CL21C300JBANNNC | SAMSUNG(三星) | C1809 | LCSC
7 | 2 | 8pF | C41,C42 | C0805 | 8pF | CL21C080DBANNNC | SAMSUNG(三星) | C170111 | LCSC
8 | 2 | 100pF | C45,C46 | C0805 | 100pF | CL21C101JBANNNC | SAMSUNG(三星) | C1790 | LCSC
9 | 1 | KF2EDGR-5.08-2P | CN1 | CONN-TH_2P-P5.08_KF2EDGR-5.08-2P |  | KF2EDGR-5.08-2P | KEFA(科发) | C441204 | LCSC
10 | 8 | KF2EDGR-3.5-3P | CN2,CN3,CN4,CN5,CN8,CN10,CN11,CN13 | CONN-TH_3P-P3.50_KF2EDGR-3.5-3P |  | KF2EDGR-3.5-3P | KEFA(科发) | C441172 | LCSC
11 | 2 | B4B-PH-K-S(LF)(SN) | CN6,CN7 | CONN-TH_B4B-PH-K-S |  | B4B-PH-K-S(LF)(SN) | JST | C131334 | LCSC
12 | 1 | B5P-VH(LF)(SN) | CN9 | CONN-TH_B5P-VH-LF-SN |  | B5P-VH(LF)(SN) | JST | C160318 | LCSC
13 | 2 | KF2EDGR-3.5-2P | CN12,CN14 | CONN-TH_P3.50_KF2EDGR-3.5-2P |  | KF2EDGR-3.5-2P | KEFA(科发) | C441171 | LCSC
14 | 1 | SMBJ18A | D1 | SMB_L4.6-W3.6-LS5.3-RD |  | SMBJ18A | OTW(联芯) | C20883324 | LCSC
15 | 1 | BZT52C10 | D2 | SOD-123_L2.7-W1.6-LS3.7-RD |  | BZT52C10 | DOWO(东沃) | C7544544 | LCSC
16 | 2 | SS34 | D3,D8 | SMA_L4.3-W2.6-LS5.1-RD |  | SS34 | Hangyu(航昱微) | C52023881 | LCSC
17 | 3 | SM712-02HTG | D4,D5,D6 | SOT-23_L2.9-W1.3-P1.90-LS2.4-BR |  | SM712-02HTG | Littelfuse(美国力特) | C172881 | LCSC
18 | 1 | PESD1CAN | D7 | SOT-23-3_L2.9-W1.3-P1.90-LS2.4-BR |  | PESD1CAN | DOWO(东沃) | C284094 | LCSC
19 | 1 | PESD3V3L1BA | D9 | SOD-323_L1.7-W1.3-LS2.5-BI |  | PESD3V3L1BA | R+O(宏嘉诚) | C54334012 | LCSC
20 | 1 | BAT54C | D11 | SOT-23-3_L2.9-W1.3-P1.90-LS2.4-BR |  | BAT54C | YONGYUTAI(永裕泰) | C51042522 | LCSC
21 | 1 | SMD1812P200TF/24 | F1 | F1812 |  | SMD1812P200TF/24 | RUILON(瑞隆源) | C434887 | LCSC
22 | 1 | SMD0805P010TF | F2 | F0805 |  | SMD0805P010TF | RUILON(瑞隆源) | C20975 | LCSC
23 | 1 | PZ254V-11-04P | H1 | HDR-TH_4P-P2.54-V-M |  | PZ254V-11-04P | XFCN(兴飞) | C2691448 | LCSC
24 | 4 | PZ254V-11-02P | JP1,JP2,JP3,JP4 | HDR-TH_2P-P2.54-V-M |  | PZ254V-11-02P | XFCN(兴飞) | C492401 | LCSC
25 | 2 | 15uH | L1,L2 | IND-SMD_L7.1-W6.5 | 15uH | SPM6530T-150M-HZ | TDK | C307809 | LCSC
26 | 6 | KT-0805G | LED1,LED2,LED3,LED4,LED5,LED6 | LED0805-R-RD |  | KT-0805G | KENTO | C2297 | LCSC
27 | 2 | AO3401A | Q1,Q2 | SOT-23-3_L2.9-W1.3-P1.90-LS2.4-BR |  | AO3401A | baocheng(宝乘) | C48678024 | LCSC
28 | 1 | 2N7002 | Q3 | SOT-23-3_L2.9-W1.3-P1.90-LS2.4-BR |  | 2N7002 | SEP(威旺) | C50176485 | LCSC
29 | 4 | 100kΩ | R1,R19,R42,R44 | R0805 | 100kΩ | 0805W8F1003T5E | UNI-ROYAL(厚声) | C149504 | LCSC
30 | 1 | 52.3kΩ | R2 | R0805 | 52.3kΩ | 0805W8F5232T5E | UNI-ROYAL(厚声) | C17740 | LCSC
31 | 11 | 10kΩ | R3,R4,R17,R18,R32,R33,R37,R38,R43,R45,R55 | R0805 | 10kΩ | 0805W8F1002T5E | UNI-ROYAL(厚声) | C38522 | LCSC
32 | 2 | 330kΩ | R5,R39 | R0805 | 330kΩ | 0805W8F3303T5E | UNI-ROYAL(厚声) | C17629 | LCSC
33 | 2 | 51.1kΩ | R6,R40 | R0805 | 51.1kΩ | 0805W8F5112T5E | UNI-ROYAL(厚声) | C17731 | LCSC
34 | 4 | 120Ω | R7,R9,R11,R13 | R0805 | 120Ω | 0805W8F1200T5E | UNI-ROYAL(厚声) | C17437 | LCSC
35 | 8 | 1kΩ | R8,R10,R12,R14,R15,R34,R35,R47 | R0805 | 1kΩ | 0805W8F1001T5E | UNI-ROYAL(厚声) | C17513 | LCSC
36 | 3 | 4.7kΩ | R16,R30,R31 | R0805 | 4.7kΩ | 0805W8F4701T5E | UNI-ROYAL(厚声) | C17673 | LCSC
37 | 1 | 31.6kΩ | R36 | R0805 | 31.6kΩ | 0805W8F3162T5E | UNI-ROYAL(厚声) | C17623 | LCSC
38 | 1 | 100Ω | R41 | R0805 | 100Ω | 0805W8F1000T5E | UNI-ROYAL(厚声) | C17408 | LCSC
39 | 1 | 150Ω | R46 | R0805 | 150Ω | 0805W8F1500T5E | UNI-ROYAL(厚声) | C17471 | LCSC
40 | 1 | 330Ω | R48 | R0805 | 330Ω | 0805W8F3300T5E | UNI-ROYAL(厚声) | C17630 | LCSC
41 | 6 | 560Ω | R49,R50,R51,R52,R53,R54 | R0805 | 560Ω | 0805W8F5600T5E | UNI-ROYAL(厚声) | C28636 | LCSC
42 | 2 | TPS54331DR | U1,U2 | SOIC-8_L5.0-W4.0-P1.27-LS6.0-BL |  | TPS54331DR | TI(德州仪器) | C9865 | LCSC
43 | 3 | MAX13487EESA+T | U3,U4,U5 | SOIC-8_L4.9-W3.9-P1.27-LS6.0-BL |  | MAX13487EESA+T | ADI(亚德诺)/MAXIM(美信) | C18347 | LCSC
44 | 1 | TJA1051T/3/1J | U6 | SOIC-8_L4.9-W3.9-P1.27-LS6.0-BL |  | TJA1051T/3/1J | NXP(恩智浦) | C38695 | LCSC
45 | 1 | STM32G0B1RET6 | U7 | LQFP-64_L10.0-W10.0-P0.50-LS12.0-BL |  | STM32G0B1RET6 | ST(意法半导体) | C2829307 | LCSC
46 | 1 | 2.4GHz | U8 | WIRELM-SMD_ESP32-C6-WROOM-1 | 2.4GHz | ESP32-C6-WROOM-1-N8 | ESPRESSIF(乐鑫) | C5366877 | LCSC
47 | 1 | FM24W256-GTR | U9 | SOIC-8_L4.9-W3.9-P1.27-LS6.0-BL |  | FM24W256-GTR | Infineon/CYPRESS(赛普拉斯) | C66020 | LCSC
48 | 1 | W25Q128JVSIQ | U10 | SOIC-8_L5.3-W5.3-P1.27-LS8.0-BL |  | W25Q128JVSIQ | Winbond(华邦) | C97521 | LCSC
49 | 1 | 12MHz | X1 | CRYSTAL-SMD_4P-L3.2-W2.5-BL | 12MHz | X322512MSB4SI | YXC(扬兴晶振) | C9002 | LCSC
50 | 1 | 32.768kHz | X2 | CRYSTAL-SMD_L3.2-W1.5-1 | 32.768kHz | SC32S-7PF20PPM | Seiko(精工) | C5452100 | LCSC

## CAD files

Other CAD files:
boards/controller-a/build/2026-09-09/board.step
boards/generator-b/build/2026-09-09/board.step
boards/controller-a/build/2026-09-09/board.dxf
boards/generator-b/build/2026-09-09/board.dxf
enclosure/blender/origin89.blend

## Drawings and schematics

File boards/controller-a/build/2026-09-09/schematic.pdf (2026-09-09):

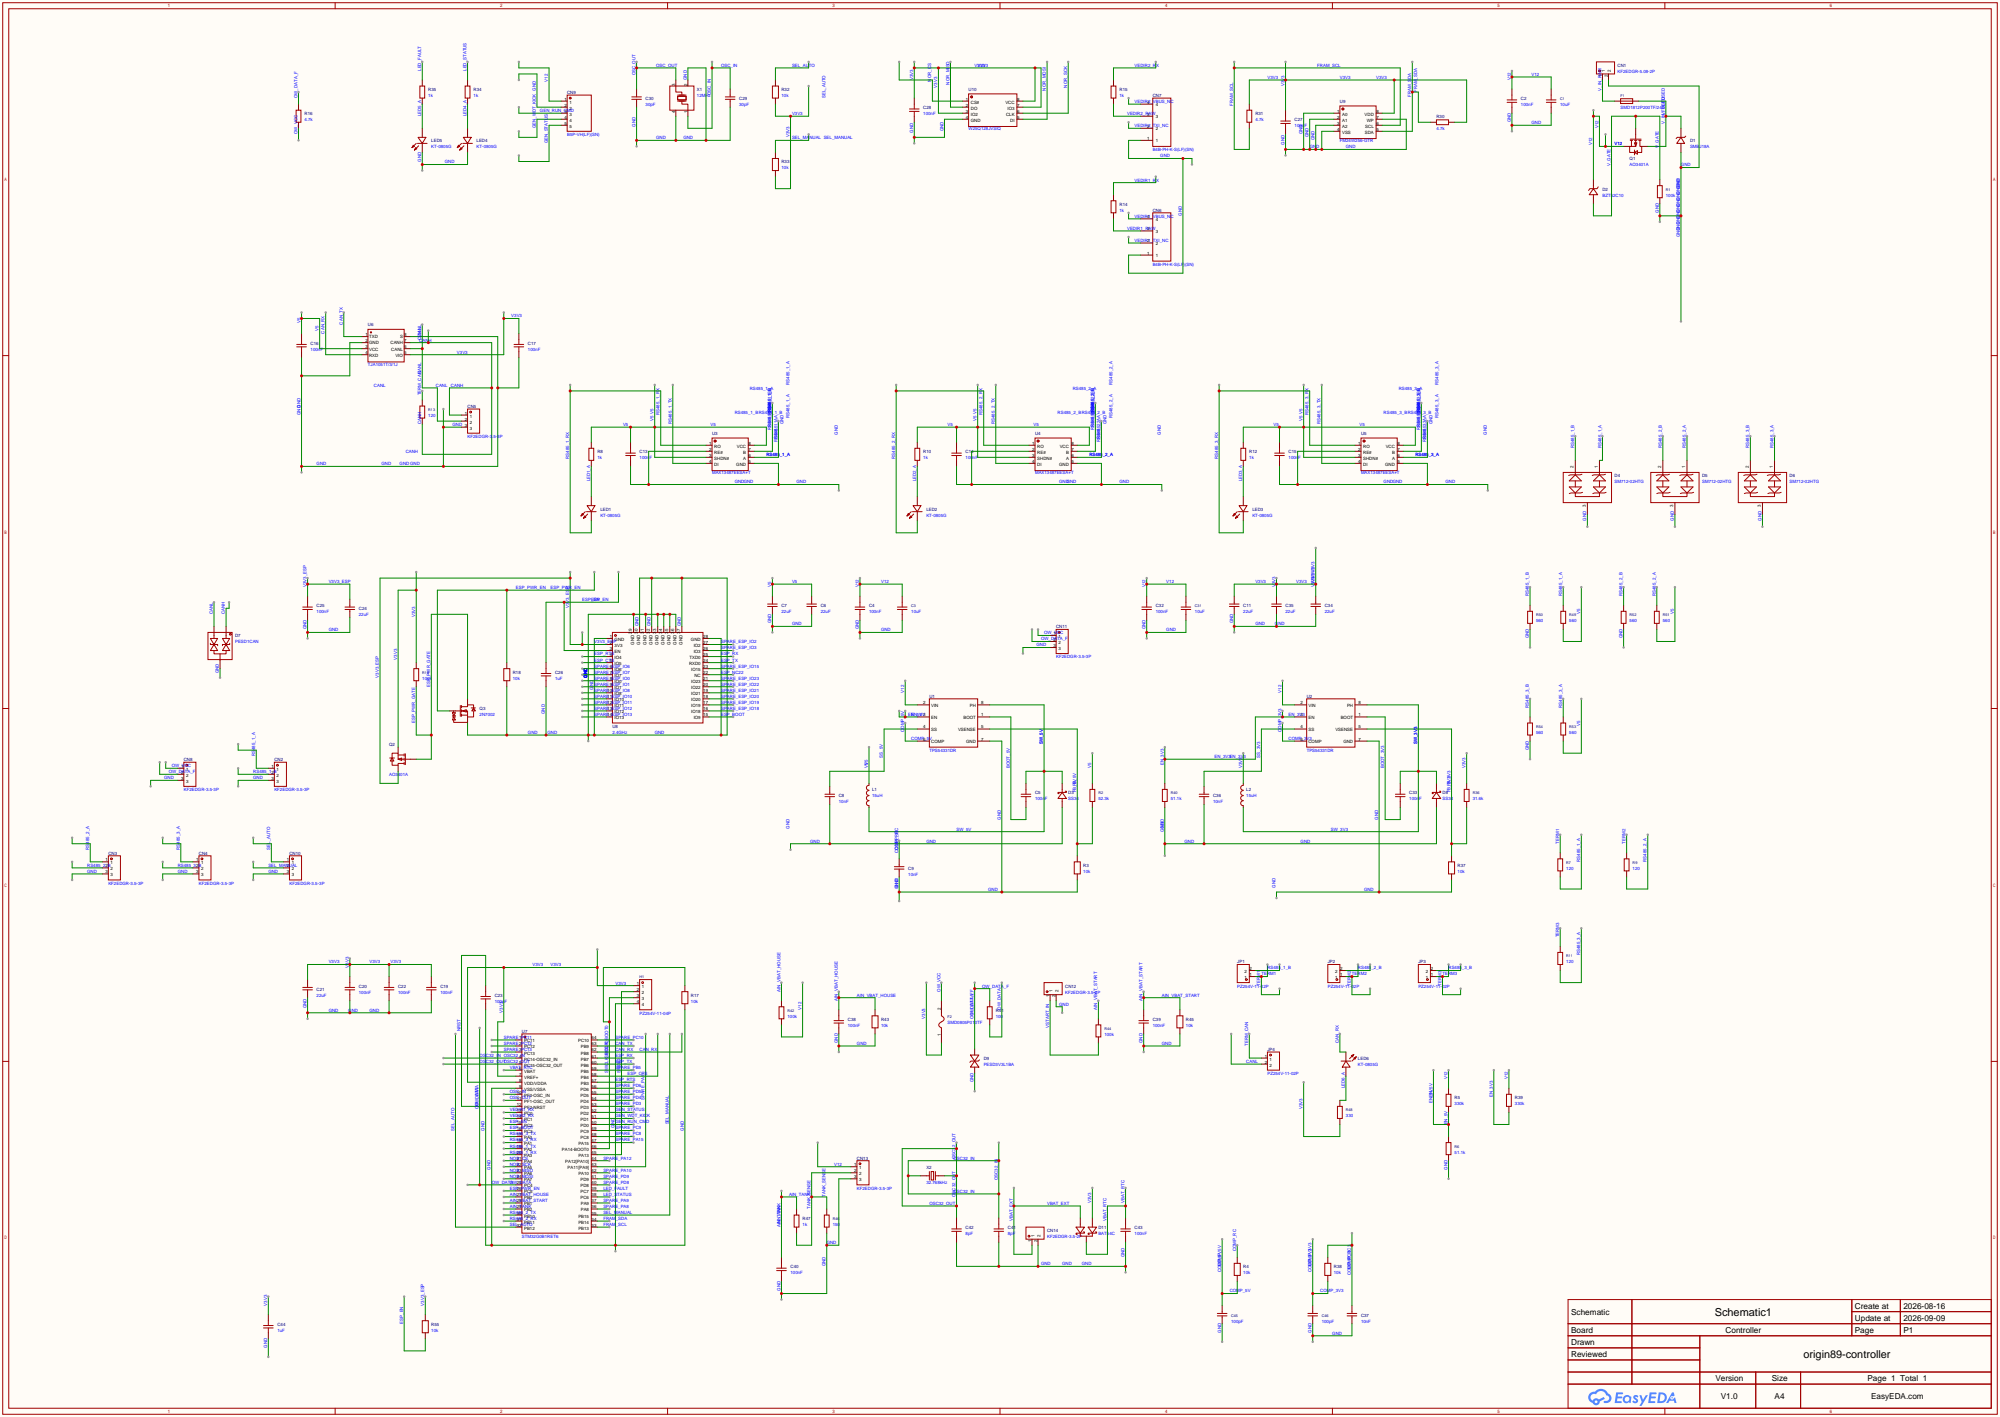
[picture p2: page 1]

GND GND GND GND GND GND GND GND GND

ESP_RX | ESP_CTS
ESP_TX
SPARE_PB5

ESP_RTS
SPARE_PD6
SPARE_PD5
SPARE_PD4
SPARE_PD3
GEN_STATUS
GEN_WDT_KICK
GEN_RUN_CMD
SPARE_PC9
SPARE_PC8
SPARE_PA15

Schematic | Schematic1 | Create at | 2026-08-16

Update at | 2026-09-09

Board | Controller | Page | P1
Drawn | | origin89-controller
Reviewed

Version | Size | Page 1 Total 1
V1.0 | A4 | EasyEDA.com

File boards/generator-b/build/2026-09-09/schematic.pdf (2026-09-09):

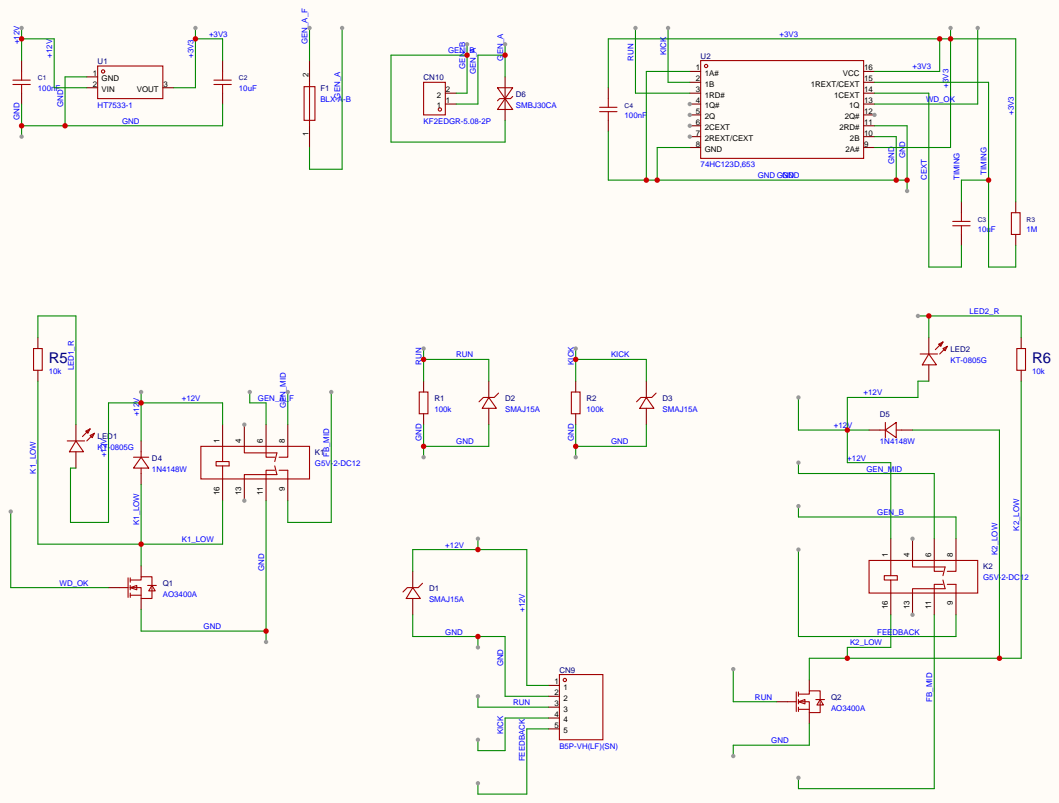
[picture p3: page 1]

Schematic | Schematic | Create at | 2026-09-01

Update at | 2026-09-09

Board | Generator | Page | P1
Drawn | | origin89-generator
Reviewed

Version | Size | Page 1 Total 1
V1.0 | A4 | EasyEDA.com

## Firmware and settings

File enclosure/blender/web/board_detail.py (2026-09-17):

"""Replace the STEP board's box components with detailed parts built from the fab files.

Imported by build_detailed_board.py inside Blender; it has no CLI of its own.

Every part comes from board A's fabrication build (FAB_BUILD, relative to the
repository root): pick-and-place gives the centre and pin 1, the footprint name gives
the package, the BOM gives the marking. The board surface uses the top copper,
pad and silkscreen masks rendered from the Gerbers by gerber_layers.mjs.

Connectors (CN*) keep the scene's existing proxies. Footprints without a builder
are printed as "unhandled footprint" and left out.
"""
import csv
import math
import random
from pathlib import Path

import bmesh
import bpy
from mathutils import Matrix, Vector

MM = 0.001
TOP = 1.69  # board top surface, mm, as imported
FAB_BUILD = 'boards/controller-a/build/2026-09-09'

# 0805 resistor values to their 4-digit marking codes.
R_CODES = {
    '100kΩ': '1003', '52.3kΩ': '5232', '10kΩ': '1002', '330kΩ': '3303', '51.1kΩ': '5112',
    '120Ω': '1200', '1kΩ': '1001', '4.7kΩ': '4701', '31.6kΩ': '3162', '100Ω': '1000',
    '150Ω': '1500', '330Ω': '3300', '560Ω': '5600',
}
MARKINGS = {
    'STM32G0B1RET6': ('STM32G0B1', 'RET6'),
    'MAX13487EESA+T': ('MAX13487', 'EESA+'),
    'TJA1051T/3/1J': ('TJA1051T/3',),
    'TPS54331DR': ('54331',),
    'FM24W256-GTR': ('FM24W256', 'G'),
    'W25Q128JVSIQ': ('25Q128JVSQ',),
    'SPM6530T-150M-HZ': ('150',),
    'SMBJ18A': ('LE',),
    'SS34': ('SS34',),
}


# ---------------------------------------------------------------- materials

def principled(name, color, rough, metal=0., coat=0., coat_rough=.1, emission=None, strength=0., transmission=0.):
    m = bpy.data.materials.get(name) or bpy.data.materials.new(name)
    m.use_nodes = True
    b = m.node_tree.nodes.get('Principled BSDF')
    b.inputs['Base Color'].default_value = (*color, 1)
    b.inputs['Roughness'].default_value = rough
    b.inputs['Metallic'].default_value = metal
    b.inputs['Coat Weight'].default_value = coat
    b.inputs['Coat Roughness'].default_value = coat_rough
    b.inputs['Transmission Weight'].default_value = transmission
    if emission:
        b.inputs['Emission Color'].default_value = (*emission, 1)
        b.inputs['Emission Strength'].default_value = strength
    return m


def materials():
    return {
        'epoxy': principled('O89 detail | IC epoxy', (.008, .008, .009), .55),
        'mark': principled('O89 detail | Laser marking', (.55, .55, .54), .8),
        'tin': principled('O89 detail | Tin leads', (.8, .8, .78), .24, metal=1.),
        'mlcc': principled('O89 detail | MLCC ceramic', (.26, .19, .12), .45),
        'r_body': principled('O89 detail | Resistor ceramic', (.5, .5, .48), .5),
        'r_top': principled('O89 detail | Resistor coat', (.012, .012, .013), .4),
        'r_print': principled('O89 detail | Resistor print', (.82, .82, .8), .7),
        'shield': principled('O89 detail | Module shield', (.72, .72, .71), .3, metal=1.),
        'etch': principled('O89 detail | Shield etching', (.05, .05, .052), .55, metal=.3),
        'fuse_print': principled('O89 detail | Fuse print', (.8, .8, .78), .7),
        'copper_ring': principled('O89 detail | Inductor winding', (.32, .17, .08), .45, metal=.5),
        'module_pcb': principled('O89 detail | Module PCB', (.012, .02, .03), .3, coat=.6),
        'module_trace': principled('O89 detail | Module antenna', (.03, .05, .07), .28, coat=.6),
        'gold': principled('O89 detail | ENIG', (.95, .72, .42), .2, metal=1.),
        'lid': principled('O89 detail | Crystal lid', (.8, .8, .79), .22, metal=1.),
        'ceramic': principled('O89 detail | Crystal base', (.75, .68, .55), .5),
        'ferrite': principled('O89 detail | Inductor body', (.045, .045, .048), .72),
        'band': principled('O89 detail | Cathode band', (.55, .55, .56), .6),
        'polyfuse': principled('O89 detail | Polyfuse', (.06, .035, .022), .45),
        'header': principled('O89 detail | Header nylon', (.02, .02, .022), .55),
        'shunt': principled('O89 detail | Shunt', (.012, .012, .013), .35),
        'led_body': principled('O89 detail | LED body', (.86, .86, .84), .35),
        'led_lens': principled('O89 detail | LED lens', (.45, .85, .35), .12, emission=(.18, .62, .39), strength=0.),
    }
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

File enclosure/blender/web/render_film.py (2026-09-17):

"""Render the website hero film: a 48 s loop (1440 frames at 30 fps) of the detailed Controller.

Runs on the scene saved by build_detailed_board.py, which Blender opens first:

    blender --background --python-exit-code 1 /tmp/home-media/controller-detailed.blend \\
      --python enclosure/blender/web/render_film.py -- --out /tmp/home-media/film

One camera moves without cuts along periodic curves through STATIONS: the
closed Controller, the cover lifting, the ESP32-C6 antenna, a light sweep along
the top copper, the STM32G0B1, the RS-485 transceivers, the exploded view
turning a full circle, reassembly and a forward flip that lands on the first
frame, so the video loops without a seam. The cover, plate, product and lights
move along monotone curves between their states instead of switching, and the
render uses motion blur. Writes transparent RGBA frame-NNNN.png files and
anchors.json (per-frame callout positions as 0-1 fractions of the frame, from
the render camera, and the window in which each callout is shown). Existing
frames are skipped, so an interrupted render resumes. The scene file is not
saved.
"""
import argparse
import json
import math
import sys
from pathlib import Path

import bpy
from bpy_extras.object_utils import world_to_camera_view
from mathutils import Quaternion, Vector

MM = .001
FPS = 30
SECONDS = 48
LENGTH = FPS * SECONDS

ANCHORS = {
    'cn': (-8., -53.6, 9.),
    'u7': (17.736, .227, 3.2),
    'antenna': (-6., 54.5, 2.6),
    'rs485': (-9.746, -38.258, 3.3),
    'board': (0., 0., 1.7),
}

# Camera stations: (seconds, aim mm, azimuth deg, elevation deg, distance mm, lens mm, f-stop).
# Periodic curves pass through every station, so the camera never cuts or stops and the last
# frame leads into the first. Azimuth is measured from +X; the terminal edge
# faces -Y.
STATIONS = [
    (0.0, (-40, -6, 12), -118, 16, 650, 60, 11),      # closed Controller, right of the hero copy
    (3.5, (-26, -6, 18), -114, 22, 560, 57, 11),
    (7.5, (-6, -8, 30), -108, 31, 460, 52, 11),       # cover lifting, terminals in view
    (10.5, (-4, 14, 14), -96, 44, 300, 48, 12),       # over the board as the cover leaves the frame
    (13.5, (-3.5, 43, 4.5), -64, 50, 95, 56, 19),     # ESP32-C6 antenna
    (16.5, (-5.6, 51, 3.5), -46, 58, 68, 58, 20),
    (18.5, (-2, 30, 2), -70, 55, 190, 42, 15),        # light sweep along the top copper
    (22.0, (2, -14, 2), -92, 50, 180, 42, 15),
    (24.5, (18.2, -.4, 3.1), -98, 40, 92, 64, 18),    # STM32G0B1, orbiting away from the white headers
    (28.0, (17.4, .6, 3.1), -128, 37, 86, 68, 18),
    (29.5, (0, -20, 3), -120, 58, 150, 52, 17),
    (31.0, (-24, -35, 3), -102, 68, 84, 50, 18),      # RS-485 transceivers, from above the terminal row
    (34.5, (6, -37, 3), -84, 66, 78, 50, 18),
    (39.5, (0, 0, 36), -118, 26, 660, 44, 11),        # exploded view turning
    (44.0, (0, 0, 26), -124, 22, 640, 48, 11),        # reassembly and flip
]

# Callout windows in seconds. HeroFilm.tsx shows a callout only inside its window.
WINDOWS = {
    'reveal': (0, 5), 'lift': (5.8, 10.2), 'u8': (13.6, 17.2), 'sweep': (18.4, 22.4),
    'u7': (24.6, 28.8), 'rs485': (30.9, 34.8), 'explode': (35.5, 43), 'assemble': (43, 48),
}
CALLOUT_ANCHORS = {'lift': 'cn', 'u8': 'antenna', 'sweep': 'board', 'u7': 'u7', 'rs485': 'rs485'}

# Object states as (seconds, value) keys, joined by monotone curves: they rest on repeated
# values and pass through the others without stopping.
COVER_MM = [(0, 0), (5, 0), (9.5, 80), (13, 300), (37, 300), (40.5, 95), (43.8, 95), (45.6, 0), (48, 0)]
PLATE_MM = [(0, 0), (38, 0), (40.5, -42), (44, -42), (45.6, 0), (48, 0)]
SPIN_DEG = [(0, 0), (38.5, 0), (44, 360), (48, 360)]
FLIP_DEG = [(0, 0), (45.5, 0), (48, 360)]
FLIP_RISE_MM = [(0, 0), (45.5, 0), (46.75, 45), (48, 0)]
# The flip turns about a level axis across the opening camera's view, through the product's centre.
FLIP_AXIS = Vector((math.cos(math.radians(-28)), math.sin(math.radians(-28)), 0))
PRODUCT_CENTRE_MM = (0, 0, 2.5)
SWEEP_POSITION = [(0, 1.08), (17.5, 1.08), (22.5, -.08), (48, -.08)]
SWEEP_LEVEL = [(0, 0), (17.2, 0), (18, 2.4), (22, 2.4), (22.8, 0), (48, 0)]
ANTENNA_GLOW = [(0, 0), (12.5, 0), (14.5, 1.6), (16.5, 1.6), (18, 0), (48, 0)]

WIDE_KEY = (-.30, .26, .34)
MACRO_KEY = (-.10, -.30, .30)
CHIP_KEY = (-.08, -.32, .30)
KEY_LIGHT = [(0, WIDE_KEY), (9.5, WIDE_KEY), (13, MACRO_KEY), (22, MACRO_KEY), (24.5, CHIP_KEY),
             (28.5, CHIP_KEY), (31, WIDE_KEY), (48, WIDE_KEY)]
# Grazing studio lights, as a fraction of their scene energy.
GRAZING = [(0, 1), (10, 1), (13, .5), (17.2, .5), (18.6, .08), (34.8, .08), (37.5, 1), (48, 1)]


def parse():
    p = argparse.ArgumentParser(description=__doc__, formatter_class=argparse.RawDescriptionHelpFormatter)
    p.add_argument('--out', type=Path, required=True)
    p.add_argument('--frames', default=f'1-{LENGTH}', help='comma-separated frames or ranges, e.g. 1-120,400')
    p.add_argument('--samples', type=int, default=40)
    p.add_argument('--size', default='1920x1080')
    p.add_argument('--anchors-only', action='store_true', help='write anchors.json without rendering')
    argv = sys.argv[sys.argv.index('--') + 1:] if '--' in sys.argv else []
    return p.parse_args(argv)


def seconds(fr):
    return (fr - 1) / FPS


def monotone(keys):
    """Piecewise cubic through (seconds, value) keys that never overshoots (Fritsch-Carlson)."""
    t = [float(k[0]) for k in keys]
    v = [float(k[1]) for k in keys]
    n = len(t)
    h = [t[i + 1] - t[i] for i in range(n - 1)]
    d = [(v[i + 1] - v[i]) / h[i] for i in range(n - 1)]
    m = [0.] * n
    for i in range(1, n - 1):
        if d[i - 1] * d[i] > 0:
            w1, w2 = 2 * h[i] + h[i - 1], h[i] + 2 * h[i - 1]
            m[i] = (w1 + w2) / (w1 / d[i - 1] + w2 / d[i])

    def at(x):
        if x <= t[0]:
            return v[0]
        if x >= t[-1]:
            return v[-1]
        i = next(j for j in range(n - 1) if x < t[j + 1])
        s = (x - t[i]) / h[i]
        return ((2 * s ** 3 - 3 * s ** 2 + 1) * v[i] + (s ** 3 - 2 * s ** 2 + s) * h[i] * m[i]
                + (-2 * s ** 3 + 3 * s ** 2) * v[i + 1] + (s ** 3 - s ** 2) * h[i] * m[i + 1])
    return at
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

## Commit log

2026-09-16 feat(enclosure): add the Blender presentation scene (#37)
    [origin89.blend]
2026-09-17 feat(enclosure): add website render scripts (#39)
2026-09-17 docs: add bench evidence for boards A and B (#40)
2026-09-17 feat(enclosure): render the hero film as one continuous shot (#41)
2026-09-17 docs: record board B's interlock passing after the relay rework (#43)
2026-09-18 docs: record twelve hours of board B endurance holds (#45)
2026-09-18 feat: add controller rev B rules and silkscreen check (#48)
2026-09-18 docs: write the generator board's revision B rules (#51)
2026-09-18 docs: bring the circuit design over from CONTROLLER-V1 (#53)
